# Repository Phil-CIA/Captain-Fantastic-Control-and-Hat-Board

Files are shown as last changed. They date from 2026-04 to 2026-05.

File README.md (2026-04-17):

# Captain Fantastic Control and HAT Board

Focused hardware repo for the **Captain Fantastic Home Edition** base control board and its companion **HAT board**.

## Scope
Originally, the system was built around two main boards:
- the **matrix board**
- the **control board**

During development, the control section was split into two physical boards:
- the **base control board**
- the **HAT board**

The HAT board is **not** a revision of the control board. It is a companion board that was created when the original control board was split for development work.

> The separate lamp/switch matrix board work lives in the dedicated repo: `Pinball-Sw-Lamp-Matrix-`.

## Repo layout
- `hardware/control-board/` – current base control-board KiCad source for the next redesign pass
- `hardware/control-board/archive/` – older control-board snapshots and backup exports kept for reference
- `hardware/hat-board/` – companion HAT-board KiCad source
- `firmware/control-board/` – clean control-board firmware baseline for this repo
- `docs/` – project status, redesign notes, firmware migration notes, and bring-up checklists

## Current firmware definition draft
- `firmware/control-board/docs/SYSTEM_BEHAVIOR_CONTRACT.md` – working behavior contract for game states, scoring, audio policy, storage budget, diagnostics, and unresolved decisions to lock before code work
- `docs/SYSTEM_BEHAVIOR_CONTRACT.md` – top-level copy of the same contract for quick review/edit from the main docs area
- `docs/SYSTEM_BEHAVIOR_CONTRACT_MATRIX_BOARD.md` – matrix-board companion contract with lockable decisions and iterative question rounds for switch/lamp protocol behavior

## Current status
- New focused repo created on **2026-04-09**
- The current KiCad files uploaded to GitHub for both boards have been merged into this cleaned repo baseline
- A **.96-inch SSD1306-style I2C OLED** has also been added as a troubleshooting display for boot messages and local status during bring-up
- The next PCB change will likely **not** be the last one; the goal is to keep building and developing the hardware while collecting more real-world feedback
- Two redesign blockers are currently tracked:
  1. the **P-channel solenoid-drive section on the base board sees gate-drive conditions above the recommended `Vgs` range when used on the 26 V supply**
  2. the **HAT-board connector did not line up with the base board**, although there is a temporary development workaround

## Next steps
1. build the board for firmware development and, if needed for proof-of-life output checks, feed **both rails from a current-limited 5 V source** rather than the real 26 V supply
2. use `docs/INITIAL_STUFFING_GUIDE.md` and `docs/BENCH_STUFFING_CHECKLIST.md` to decide what to populate now versus later
3. follow the safe bring-up procedure in `docs/FIRST_POWERUP_CHECKLIST.md`
4. proceed with the **single-channel `TPS1H200A-Q1` smart high-side** respin direction using `docs/SOLENOID_DRIVER_SELECTION.md`, `docs/SINGLE_CHANNEL_SOLENOID_LAYOUT.md`, and `docs/SMART_SWITCH_CHANNEL_BLOCK.md` while continuing the clean firmware migration in `firmware/control-board/`

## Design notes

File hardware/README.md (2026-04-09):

# Hardware Notes

This folder contains the hardware design files for the Captain Fantastic base control board and its companion HAT board.

## Contents
- `control-board/` – current base control-board KiCad project and related files
- `control-board/archive/` – older control-board snapshots and backup exports kept for reference
- `hat-board/` – companion HAT-board KiCad project

## Guidance
- The HAT board is **not** a revision of the control board; it was created when the original control board was split during development.
- Treat the uploaded KiCad files now stored under `hardware/` as the **authoritative baseline** for the next redesign pass.
- As redesign decisions are made, keep the active source clearly identified and move stale artifacts out of the way.

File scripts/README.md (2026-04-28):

# BOM Conversion Scripts

## jlc_to_digikey_bom.py

Converts an existing JLC-style BOM CSV or LCSC quotation XLS into:

- a Digi-Key upload CSV that only contains safe rows with real part-number identity
- a Digi-Key candidate BOM CSV
- an unresolved-items CSV for rows that still need lookup or manual review

This is intended to preserve the current KiCad to JLC export workflow and move the Digi-Key conversion into a post-export step.

### Usage

```powershell
c:/Users/forch/GitHub/Captain-Fantastic-Control-and-Hat-Board/docs/.venv/Scripts/python.exe scripts/jlc_to_digikey_bom.py "c:/path/to/project BOM.csv"
```

LCSC quotation workbook input:

```powershell
c:/Users/forch/GitHub/Captain-Fantastic-Control-and-Hat-Board/docs/.venv/Scripts/python.exe scripts/jlc_to_digikey_bom.py "c:/Users/forch/Downloads/export_project_20260424_030448.xls"
```

Optional lookup table:

```powershell
c:/Users/forch/GitHub/Captain-Fantastic-Control-and-Hat-Board/docs/.venv/Scripts/python.exe scripts/jlc_to_digikey_bom.py "c:/path/to/project BOM.csv" --lookup-csv scripts/commodity_lookup_template.csv
```

Optional reusable cross-reference sheet:

```powershell
c:/Users/forch/GitHub/Captain-Fantastic-Control-and-Hat-Board/docs/.venv/Scripts/python.exe scripts/jlc_to_digikey_bom.py "c:/Users/forch/Downloads/export_project_20260424_030448.xls" --cross-reference-csv "c:/Users/forch/Downloads/export_project_20260424_030448_Cross_Reference.csv"
```

Optional master reusable cross-reference sheet:

```powershell
c:/Users/forch/GitHub/Captain-Fantastic-Control-and-Hat-Board/docs/.venv/Scripts/python.exe scripts/jlc_to_digikey_bom.py "c:/Users/forch/OneDrive/JLCPCB files/Pinnall Control Board/Hat Board/Hat board BOM.csv" --master-cross-reference-csv "c:/Users/forch/OneDrive/JLCPCB files/master_cross_reference.csv"
```

### Output files

For an input file named `Project BOM.csv`, the script writes:

- `Project_BOM_DigiKey_Upload.csv`
- `Project_BOM_DigiKey_Simple_Upload.csv`
- `Project_BOM_DigiKey_Candidate_BOM.csv`
- `Project_BOM_Unresolved.csv`

The files are written next to the source BOM unless `--output-dir` is provided.

### Status values

- `Auto`: manufacturer and manufacturer part number were already present and carried through.
- `Lookup`: the row looks like a commodity passive and should be resolved through a preferred Digi-Key mapping.
- `Manual_Review`: fit-critical, generic, or incomplete rows that should not be guessed.

### Cross-reference guidance

- Use `--cross-reference-csv` to feed the reusable review sheet built by `build_cross_reference_sheet.py` directly into the converter.
- Use `--master-cross-reference-csv` to feed the combined reusable master sheet built by `build_master_cross_reference_sheet.py` into the converter.
- The converter matches cross-reference sheets by `LCSC_PN` first and `Manufacturer_PN` second.
- If both `--cross-reference-csv` and `--master-cross-reference-csv` are provided, the project sheet wins and the master sheet is only used as fallback.
- If a row in the cross-reference sheet has `DigiKey_PN`, that value is treated as the preferred Digi-Key identity.
- If `DigiKey_PN` is blank but `Onshore_Preferred_PN` is populated with supplier `Digi-Key` or left blank, the converter will also treat that as a Digi-Key-safe preferred part number.
- Candidate and unresolved outputs now include `Preferred_Onshore_PN`, `Preferred_Onshore_Supplier`, and `Cross_Reference_Match` columns so you can see exactly where the mapping came from.

### Upload guidance

- Use the `*_DigiKey_Upload.csv` file for Digi-Key import tests.
- If Digi-Key keeps importing the wrong identity from a wide CSV, use `*_DigiKey_Simple_Upload.csv` first. It contains only `Manufacturer Part Number`, `Quantity`, and `Manufacturer Name` to reduce mapping ambiguity.
- Use the `*_DigiKey_Candidate_BOM.csv` file as a review sheet, not as the first upload target.
- The upload CSV intentionally omits unresolved rows so Digi-Key does not try to match reference designators like `D1` or `J4` as if they were part numbers.
- If you have an LCSC `export_project_*.xls` quotation workbook, prefer that over the raw KiCad/JLC BOM CSV. It already contains LCSC matched manufacturer part numbers and produced a much stronger Digi-Key upload file in validation.

### Current limitations

- The script does not yet fetch Digi-Key part numbers from the web.
- Commodity passives need a lookup table or manual preferred-stock assignment to fill `DigiKey_PN`.
- Connector, module, display, and other fit-critical items are intentionally conservative and stay in `Manual_Review` unless the source BOM already has reliable data.

## build_commodity_lookup_candidates.py

Scans one BOM or a directory tree of BOMs and produces a normalized passive lookup-candidates CSV.

### Usage

```powershell
c:/Users/forch/GitHub/Captain-Fantastic-Control-and-Hat-Board/docs/.venv/Scripts/python.exe scripts/build_commodity_lookup_candidates.py "c:/Users/forch/OneDrive/JLCPCB files"
```

This writes `commodity_lookup_candidates.csv` in the input directory by default.

Use this first if you do not already have a preferred Digi-Key passive list. It gives you one compact table of recurring passive specs to validate, instead of forcing you to review every project BOM separately.

## build_cross_reference_sheet.py

Builds a reusable cross-reference sheet from an LCSC `export_project_*.xls` quotation workbook.

### Usage

```powershell
c:/Users/forch/GitHub/Captain-Fantastic-Control-and-Hat-Board/docs/.venv/Scripts/python.exe scripts/build_cross_reference_sheet.py "c:/Users/forch/Downloads/export_project_20260424_030448.xls"
```

This writes `*_Cross_Reference.csv` next to the source workbook by default.

### Purpose

- Use this when Digi-Key import coverage is too low to be practical.
- The output is a deduplicated review sheet with LCSC part number, manufacturer, manufacturer part number, package, stock information, and blank columns for Digi-Key, Mouser, or another onshore preferred source.
- Fill this sheet once and reuse it across future builds instead of repeating cross-references project by project.

## build_digikey_cross_reference_sheet.py

Builds the first Digi-Key-history-seeded master cross-reference sheet from a standard Digi-Key order CSV export.

### Usage

```powershell
c:/Users/forch/GitHub/Captain-Fantastic-Control-and-Hat-Board/docs/.venv/Scripts/python.exe scripts/build_digikey_cross_reference_sheet.py "c:/path/to/digikey_order_history.csv"
```

This writes `*_DigiKey_Cross_Reference.csv` next to the source CSV by default.

### Expected input shape

The script targets the standard Digi-Key order CSV column shape:

- `Index`
- `DigiKey Part #`
- `Manufacturer Part Number`
- `Description`
- `Customer Reference`
- `Quantity`
- `Backorder`
- `Unit Price`
- `Extended Price`

### Purpose

- Use this as the Digi-Key-first seed dataset for the master sourcing sheet.
- It deduplicates rows by manufacturer part number when available, rolls up purchased quantity across repeated orders, and preserves the preferred Digi-Key ordering code.
- It intentionally leaves `LCSC_PN` and `Preferred_JLC` blank so the same sheet can be enriched later from LCSC quote workbooks.
- The standard Digi-Key CSV does not include manufacturer name or order date, so those fields are left blank or inferred conservatively until a richer export is available.

## build_master_cross_reference_sheet.py

Builds one combined reusable cross-reference sheet from a directory tree of JLCPCB project BOMs and LCSC quote workbooks.

### Usage

```powershell
c:/Users/forch/GitHub/Captain-Fantastic-Control-and-Hat-Board/docs/.venv/Scripts/python.exe scripts/build_master_cross_reference_sheet.py "c:/Users/forch/OneDrive/JLCPCB files"
```

This writes `master_cross_reference.csv` in the input directory by default.

### Supported inputs

- project BOM CSVs with columns like `Reference`, `Qty`, `Value`, `Footprint`, `LCSC`, and `Manufacturer`
- LCSC quotation `.xls` workbooks
- LCSC quotation `.xlsx` workbooks

### Purpose

- Use this when you want one master sourcing sheet instead of maintaining one cross-reference sheet per project.
- The script scans the directory tree, skips existing Digi-Key output CSVs, deduplicates repeated parts, and preserves which source files contributed each row.
- Rows from richer LCSC quote workbooks win over plain project BOM CSV rows when the same part appears in both places.

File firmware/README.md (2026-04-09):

# Firmware

Firmware work for this repo will live here as it is separated from the older mixed-purpose Captain Fantastic repository.

## Current contents
- `control-board/` – clean bring-up baseline plus legacy reference import for the base control board

## Plan
- keep the new active firmware clean and hardware-focused
- merge only the useful parts from the previous repo
- avoid dragging over old experimental clutter unless it is still needed

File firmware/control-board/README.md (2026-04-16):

# Control-Board Firmware

This folder is the clean firmware starting point for the **Captain Fantastic base control board** in this repo.

## Purpose
- keep a **clean bring-up-oriented `main.cpp`** for the new board work
- preserve the older control firmware as a **reference import** for merging features back in gradually
- support the current development plan: **build the full board, power both rails at 5 V for now if needed, and keep the real 26 V solenoid supply out of service**

## Layout
- `src/main.cpp` – integration orchestrator for runtime subsystems
- `src/command/command_runtime.cpp` – serial polling entrypoint and command dispatch
- `src/command/input_commands.cpp` – direct input command handlers
- `src/command/ota_commands.cpp` – OTA command handlers
- `src/command/audio_commands.cpp` – audio command handlers
- `src/display/displays.cpp` – migrated 7-segment display helper
- `src/input/direct_input_runtime.cpp` – direct input polling and state cache runtime
- `src/input/input_overlay_runtime.cpp` – direct-input overlay formatting, idle refresh, and event/status trigger glue
- `src/ota/ota_runtime.cpp` – staged OTA + Wi-Fi maintenance runtime
- `src/audio/audio_runtime.cpp` – MP3 playback, storage sync, and I2S fallback runtime
- `include/` – copied configuration and protocol headers needed for the control-board codebase
- `reference/legacy_control_main.cpp` – previous larger control firmware kept only as a source to merge from
- `docs/FIRMWARE_MODES_AND_SPLIT_2026-04-16.md` – system/test profile split contract
- `docs/CHAT_MEMORY_2026-04-16.md` – session memory and decisions captured in-repo

## Build profiles
The firmware now supports profile-based builds:
- `captain_control_system` (default): integration-safe behavior
- `captain_control_test`: test-heavy behavior and deeper diagnostics
- `captain_control_bringup`: retained for compatibility while migration continues

Profile selection is controlled by `CAPTAIN_APP_MODE_TEST` via `include/app_mode_config.h`.

Quick commands:
1. `platformio run -e captain_control_system`
2. `platformio run -e captain_control_test`

## Bring-up intent
The new `main.cpp` is intentionally minimal:
- boots the MCU
- initializes I2C and the score display
- scans the I2C bus and brings up the added **.96-inch SSD1306-style OLED** for local boot/status text when present
- keeps the solenoid outputs in a safe default state
- allows optional low-voltage output proof-of-life testing only when intentionally enabled

## Next firmware steps
1. separate test-only command behavior from shared command handlers while preserving one serial entrypoint
2. move over only the working gameplay / display / input pieces from `reference/legacy_control_main.cpp`
3. keep hardware-specific experiments and dead ends out of the system profile path
4. add the revised board pin or feature changes as they are confirmed on hardware

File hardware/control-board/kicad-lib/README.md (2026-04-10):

# Local KiCad Library (Repo-Tracked)

Put third-party symbols and footprints for this board here so paths are stable and git-tracked.

## Folder layout
- `symbols/` -> `.kicad_sym` files
- `footprints/` -> `.pretty` folders containing `.kicad_mod` files
- `3dmodels/` -> optional `.step` or `.wrl` files

## Recommended SnapMagic import naming
- symbol library file: `symbols/Snapmagic_TPS1H200A_Q1.kicad_sym`
- footprint library folder: `footprints/Snapmagic_TI_TPS1H200A_Q1.pretty/`

## KiCad path setup
In KiCad, when adding the library paths, use project-variable form so links survive on other machines:
- symbol library path: `${KIPRJMOD}/kicad-lib/symbols/Snapmagic_TPS1H200A_Q1.kicad_sym`
- footprint library path: `${KIPRJMOD}/kicad-lib/footprints/Snapmagic_TI_TPS1H200A_Q1.pretty`

`KIPRJMOD` resolves to the folder that contains the `.kicad_pro` file.

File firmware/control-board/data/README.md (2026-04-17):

# Control-Board Audio Test Files

Place MP3 files for control-board event playback here, then upload SPIFFS.

Recognized filenames (first match wins by event):

- Startup: `startup.mp3`, `rocket_man.mp3`, `crocodile_rock.mp3`
- Attract loop: `attract.mp3`, `rocket_man.mp3`
- Game start: `start.mp3`, `crocodile_rock.mp3`
- Bonus: `bonus.mp3`, `crocodile_rock.mp3`
- Game over: `game_over.mp3`, `rocket_man.mp3`
- High score: `high_score.mp3`, `rocket_man.mp3`

Upload steps from `firmware/control-board/`:

```powershell
pio run -e captain_control_bringup -t buildfs
pio run -e captain_control_bringup -t uploadfs
```

Current firmware behavior:

- On boot, firmware tries Startup MP3 once through MAX98357 I2S.
- You can trigger event clips from serial monitor with commands:
	- `mp3 help`
	- `mp3 startup`
	- `mp3 attract` (loops)
	- `mp3 start`
	- `mp3 bonus`
	- `mp3 gameover`
	- `mp3 hiscore`
	- `mp3 stop`
- If no suitable MP3 file exists for startup, firmware falls back to the built-in startup tone test.

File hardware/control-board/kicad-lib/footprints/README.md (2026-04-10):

# Footprints

Put project-specific KiCad footprint libraries here as `.pretty` folders.

Example for this work:
- `Snapmagic_TI_TPS1H200A_Q1.pretty/`

This file exists so the folder is tracked and visible in git/GitHub.

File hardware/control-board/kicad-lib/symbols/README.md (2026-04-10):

# Symbols

Put project-specific `.kicad_sym` files here.

Example for this work:
- `Snapmagic_TPS1H200A_Q1.kicad_sym`

This file exists so the folder is tracked and visible in git/GitHub.

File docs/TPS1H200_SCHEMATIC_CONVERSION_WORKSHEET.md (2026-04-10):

# TPS1H200 Schematic Conversion Worksheet

This worksheet is the direct bridge from the current discrete solenoid block to five repeated `TPS1H200A-Q1` channels.

Use this during an interactive KiCad schematic edit session.

## Scope
- Replace the old discrete solenoid drive path centered on `Q10`, `Q11`, and `Q18`
- Implement five channels for `S2`..`S6`
- Keep firmware-facing control naming aligned with `SD2`..`SD6`

## Existing anchor points in the current schematic
- old references:
  - `Q11` at [hardware/control-board/Pinball Control board.kicad_sch](hardware/control-board/Pinball%20Control%20board.kicad_sch#L33903)
  - `Q10` at [hardware/control-board/Pinball Control board.kicad_sch](hardware/control-board/Pinball%20Control%20board.kicad_sch#L41791)
  - `Q18` at [hardware/control-board/Pinball Control board.kicad_sch](hardware/control-board/Pinball%20Control%20board.kicad_sch#L42519)
- control/output rail labels already present:
  - `SD2` at [hardware/control-board/Pinball Control board.kicad_sch](hardware/control-board/Pinball%20Control%20board.kicad_sch#L11548)
  - `SD3` at [hardware/control-board/Pinball Control board.kicad_sch](hardware/control-board/Pinball%20Control%20board.kicad_sch#L11658)
  - `SD4` at [hardware/control-board/Pinball Control board.kicad_sch](hardware/control-board/Pinball%20Control%20board.kicad_sch#L12252)
  - `SD5` at [hardware/control-board/Pinball Control board.kicad_sch](hardware/control-board/Pinball%20Control%20board.kicad_sch#L12164)
  - `SD6` at [hardware/control-board/Pinball Control board.kicad_sch](hardware/control-board/Pinball%20Control%20board.kicad_sch#L11944)
  - `S2` at [hardware/control-board/Pinball Control board.kicad_sch](hardware/control-board/Pinball%20Control%20board.kicad_sch#L12208)
  - `S3` at [hardware/control-board/Pinball Control board.kicad_sch](hardware/control-board/Pinball%20Control%20board.kicad_sch#L12032)
  - `S4` at [hardware/control-board/Pinball Control board.kicad_sch](hardware/control-board/Pinball%20Control%20board.kicad_sch#L11636)
  - `S5` at [hardware/control-board/Pinball Control board.kicad_sch](hardware/control-board/Pinball%20Control%20board.kicad_sch#L11900)
  - `S6` at [hardware/control-board/Pinball Control board.kicad_sch](hardware/control-board/Pinball%20Control%20board.kicad_sch#L12010)
  - `+22vdc` at [hardware/control-board/Pinball Control board.kicad_sch](hardware/control-board/Pinball%20Control%20board.kicad_sch#L11592)

## Channel mapping to apply
| Channel | Control net | Output net | Supply net |
| --- | --- | --- | --- |
| U_S2 | SD2 | S2 | +22vdc |
| U_S3 | SD3 | S3 | +22vdc |
| U_S4 | SD4 | S4 | +22vdc |
| U_S5 | SD5 | S5 | +22vdc |
| U_S6 | SD6 | S6 | +22vdc |

## Required per-channel support items
- local decoupling capacitor at device supply pin
- CL programming population (value per bench tuning)
- DELAY configuration population (mode per bench tuning)
- FAULT routing to test point and optional MCU net

## Execution checklist
1. Add/import `TPS1H200A-Q1` symbol to the project schematic library.
2. Place five channel symbols (`U_S2`..`U_S6`) near existing solenoid output region.
3. Rewire control nets: `SD2`..`SD6` to channel inputs.
4. Rewire outputs: channel outputs to `S2`..`S6`.
5. Rewire supply and return: `+22vdc` and ground per channel.
6. Add CL, DELAY, and FAULT support components per channel.
7. Remove legacy discrete path parts no longer used (`Q10`, `Q11`, `Q18`, and dependent gate-drive parts).
8. Run ERC and resolve all new issues.
9. Mirror chosen CL/DELAY settings in `docs/TPS1H200_CL_DELAY_BENCH_TABLE.md`.

## Note on tooling
The project currently does not include a dedicated `.kicad_sym` library in-repo, so symbol insertion is best done interactively in KiCad to avoid malformed schematic edits.

## SnapMagic import and repo sync steps
Use this flow to keep your local KiCad setup and git repo aligned.

1. Copy your downloaded SnapMagic symbol file into:
  - `hardware/control-board/kicad-lib/symbols/`
2. Copy your downloaded SnapMagic footprint `.pretty` folder into:
  - `hardware/control-board/kicad-lib/footprints/`
3. In KiCad Schematic Editor, open **Preferences -> Manage Symbol Libraries**.
4. Add your symbol library as **Project Specific** and paste this in the path/address box:
  - `${KIPRJMOD}/kicad-lib/symbols/<your_symbol_file>.kicad_sym`
5. In KiCad PCB Editor (or Preferences), open **Manage Footprint Libraries**.
6. Add your footprint library as **Project Specific** and paste this in the path/address box:
  - `${KIPRJMOD}/kicad-lib/footprints/<your_footprint_library>.pretty`
7. Save library tables and place the symbol in schematic.
8. In terminal, run:
  - `git add hardware/control-board/kicad-lib`
  - `git add hardware/control-board/Pinball Control board.kicad_sch`
  - `git add hardware/control-board/Pinball Control board.kicad_pcb`
  - `git commit -m "Add project-local TPS1H200 symbol and footprint libraries"`
  - `git push`

This keeps your symbol and footprint paths portable and tracked in the repo.

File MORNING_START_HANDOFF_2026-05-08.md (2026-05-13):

# Morning Start Handoff - 2026-05-08

Status: Ready for next-session execution.
Purpose: Start clean in the morning with one practical sequence that gets from bring-up toward playable behavior while keeping repo hygiene moving.

## Repositories In Scope
1. https://github.com/Phil-CIA/Captain-Fantastic-Control-and-Hat-Board
2. https://github.com/Phil-CIA/Pinball-Sw-Lamp-Matrix-
3. https://github.com/Phil-CIA/Captain-Fantastic-home-edition

## Current Snapshot

### Control-and-Hat-Board (main at d07bf7c)
- New handoff present: SOLENOID_BRINGUP_HANDOFF_2026-05-08.md
- Solenoid state:
  - S3/S4/S5/S6 working on TPS path
  - S2 (outhole) still insufficient force on TPS even with aggressive current-limit tuning
- Firmware currently in test profile behavior for focused S2 validation:
  - S2 pulse set to 100 ms
  - Single-channel repeated test mode enabled
- GPIO init-order fix applied to reduce boot glitch risk on GPIO5 path

### Pinball-Sw-Lamp-Matrix- (main at b2cbb86)
- Deterministic row scheduler and SR timing stabilization work already merged previously
- CI pin fix for espressif32 version already merged previously
- Latest commit is doc-only

### Captain-Fantastic-home-edition
- Not locally checked out in this workspace during this session
- Still part of integration scope as legacy behavior reference source

## Morning Start Plan (Execution Order)

1. Hardware path first: complete S2 outhole relay workaround bench wiring and validate force.
2. After S2 force is reliable, revert control test loop from single-channel S2 back to full five-channel cycle and confirm all five channels repeat cleanly.
3. Verify the four pending switch paths explicitly and log results:
   - Tilt
   - Maintenance/Test
   - Easy
   - Start
4. Define and lock operating mode behavior notes before deeper gameplay coding:
   - Boot
   - Test/Service
   - Attract
   - Gameplay
   - Degraded/Error
5. Begin gameplay coupling implementation once switch and mode behavior checks are captured:
   - Switch edge to solenoid action mapping
   - Initial score increment path
   - Lamp state update path

## Repo Cleanup Stream (Run In Parallel)

1. In each repo, create a dedicated handoff archive folder.
2. Move handoff/transfer session docs into that folder without renaming date-stamped files.
3. Add one chronological journey index per repo linking all handoffs in date order.
4. Refresh stale top-level status docs after technical state is validated.

## Immediate First Commands For Morning

1. Pull all repos on start:
   - Control-and-Hat-Board
   - Pinball-Sw-Lamp-Matrix-
   - Captain-Fantastic-home-edition
2. Build and flash control-board test profile to verify baseline before hardware edits.
3. Execute relay workaround validation checklist from SOLENOID_BRINGUP_HANDOFF_2026-05-08.md.

## Risks To Watch

- Do not start gameplay callback wiring while S2 hardware force is unresolved.
- Keep test-mode changes isolated and reversible so production path is not polluted.
- Preserve historical handoff filenames when reorganizing docs to avoid losing timeline continuity.

## Session End State

- Handoff written and pushed target: this file
- Next operator action: begin at Morning Start Plan step 1

## Switch Recovery Addendum (2026-05-11)

### What We Know

1. Known-good matrix checkpoint exists from the working perspective: `aca9ac0` (matrix chunked OLED milestone, 2026-05-05).
2. Latest handoff (2026-05-10) indicates transport health is stable:
   - `rx_pkts` increasing on matrix
   - `wr_ok` and `rd_ok` increasing on control
   - checksum/reject alarms no longer noisy
3. Current failure mode is switch isolation/mapping quality, not basic link up/down.
4. Current control firmware has a strict burst-drop guard (`MATRIX_MAX_RISING_EDGES_PER_POLL = 4`) that can suppress entire poll windows.
5. Mapping-mode concept (lamps forced off during mapping capture) is a valid mitigation and must be verified in the exact flashed binary before further tuning.

### What We Need To Know

1. Are real switch presses being dropped by filtering thresholds (control side) versus lost on matrix scan/debounce (matrix side)?
2. Is lamp-off mapping mode active in the actual build being tested?
3. Did row/column mapping or active-row assumptions drift between `aca9ac0` and current cleanup state?
4. Do dropped-burst counts correlate directly with deliberate press windows?
5. Is the current debounce cadence suppressing short but valid press events?

### Recovery-First Plan (No Gameplay Features Until This Passes)

1. Freeze A/B references:
   - A = known-good behavior target (`aca9ac0`)
   - B = current behavior target (latest split-protocol head)
2. Run identical captures for A and B on same hardware and wiring:
   - 30s quiet baseline
   - 15-20 deliberate presses on one target switch
   - repeat on two additional switches
3. Compare outcomes:
   - If A clean and B fails, software regression confirmed.
   - If both fail, prioritize hardware/wiring/mechanics isolation.
4. If software regression is confirmed, isolate in this order:
   - force lamp-off mapping mode
   - temporarily relax burst-drop threshold for capture build
   - reduce debounce ticks for capture build
   - verify row/col mapping and active-row limits
5. Lock acceptance gate before gameplay coupling resumes:
   - each tested switch yields one dominant bit in press windows
   - intentional presses are not suppressed by burst filter

### Hard Stop Rule

Do not proceed to scoring, gameplay callback wiring, or mode expansion until the switch recovery acceptance gate is met and repeatable.

---

## Integration Reference: Recovery-to-Gameplay Plan (May 12–13)

A comprehensive next-phase execution plan has been created to advance from baseline validation (timing locked, I2C healthy, S3–S6 solenoid working) toward playable behavior.

**See**: [RECOVERY_TO_GAMEPLAY_PLAN_2026-05-12.md](RECOVERY_TO_GAMEPLAY_PLAN_2026-05-12.md)

### Key Highlights from That Plan

1. **What We Know** (May 12 End-of-Day Status)
   - Matrix timing locked and acceptance test passed
   - I2C transport stable under continuous polling
   - Solenoid S3–S6 verified working on TPS
   - S2 relay workaround pending installation (parallel stream, not blocking)

2. **What We Need To Know** (Blocking Criteria)
   - Switch detection quality: one dominant bit per press (A/B capture validation required)
   - Tilt & Start direct-input paths clean (no cross-talk with matrix)
   - Lamp delivery to headbox working without frame corruption

3. **S2 Coil Protection Policy** (During Relay Installation & Limited Testing)
   - Max 2–3 activations per group
   - 10–15s cool-down between attempts
   - 60s cool-down between groups
   - Operator observes coil temperature/sound for abort signals
   - Policy suspended after relay installation complete

4. **Parallel Work Streams** (May 13–14, ~6–8 hours total)
   - **Stream A (Hardware)**: Install S2 relay, verify 24V force recovery (~2–4 hours)
   - **Stream B (Software)**: Execute switch A/B capture validation, run gate analysis, apply feature gates if needed (~4–6 hours)

5. **Gameplay Integration** (Begins After Switch Gate Passes)
   - Mode scaffolding (Boot → Test → Attract → Gameplay → Error)
   - Solenoid coupling (switch edge → solenoid action)
   - Score & lamp state wiring

6. **Definition of Done**
   - Switch validation gate passed ✅
   - S2 coil protection enforced or relay installed ✅
   - One end-to-end switch→solenoid→lamp flow working ✅
   - All docs updated and pushed ✅

**Execution Sequence**: Start with parallel streams (relay install + switch captures). Switch gate result drives gameplay integration timeline. Reference that plan for detailed command sequences, feature gates, and risk mitigations.

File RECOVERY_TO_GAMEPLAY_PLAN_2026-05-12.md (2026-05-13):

# Recovery-to-Gameplay Integration Plan — 2026-05-12

**Status**: Ready for immediate execution (May 13–14).  
**Purpose**: Advance from hardware validation baseline (matrix timing locked, I2C link healthy, S3–S6 solenoid working) to playable behavior while managing parallel hardware work (S2 relay installation) and switch validation gates.

---

## What We Know (As of May 12 End-of-Day)

✅ **Matrix Timing Baseline Locked**
- Deterministic row scheduler: Blank=50µs, Settle=50µs, Hold post-settle
- One-row-active invariant maintained
- Acceptance test passed (no timing violations detected over 60s baseline)
- Checkpoint commit: `ec90aa2` (home-edition) with timing contract doc

✅ **I2C Transport Healthy**
- Matrix slave at 0x24 stable under continuous polling
- Control master at 100 kHz polls every 15ms without checksum/rejection alarm noise
- Packet counters (`rx_pkts`, `wr_ok`, `rd_ok`) increasing monotonically
- Burst filter active: 4-rising-edge-per-poll threshold suppresses scan noise

✅ **Solenoid S3–S6 Verified**
- TPS1H200A driver path working for kitchen drop (S3), orbit (S4), ramp (S5), scoop (S6)
- Pulse widths {45, 45, 45, 40} ms confirmed in hardware testing
- Force/behavior observed as expected on bench

⚠️ **Solenoid S2 (Outhole) in Workaround**
- TPS1H200A current-limit insufficient even at 0Ω (coil/hardware constraint)
- Relay solution implemented: GPIO23 → automotive 24V relay, full 24V fed to outhole solenoid
- **Relay installation NOT YET COMPLETE** (happening May 13 in parallel)
- Until relay installed: **S2 protected by manual testing limits** (see S2 Coil Protection Policy below)

✅ **Matrix LED Heartbeat Implemented**
- WS2812 RGB status LED on GPIO8 via native RMT
- Green = healthy, Red = I2C fault
- 500ms toggle cadence

✅ **Control Board Heartbeat GPIO Conflict Fixed**
- Moved from GPIO2 (hardware conflict with headbox 74HC595 DATA line) to GPIO16
- No impact on matrix communication

---

## What We Need To Know (Blocking Criteria for Gameplay)

### 1. Switch Detection Quality & Dominance
**Criterion**: One dominant bit per switch, no suppression of real presses by filtering.

- **Current State**: Multiple bits rising per press window; unclear which is true signal vs. noise
- **Method**: A/B capture on both machines
  - A = known-good checkpoint (`aca9ac0`, matrix milestone from May 5)
  - B = current code (May 12 head)
  - Identical hardware wiring, same test sequence
  - 30s quiet baseline + 15–20 deliberate presses per switch on 3 target switches
- **Expected Result**: A shows 1 dominant bit per press, B either matches or shows clear regression pattern
- **Acceptance Gate**: Must demonstrate either current code passes OR clear root cause (burst threshold too strict, debounce too conservative, mapping mode off)

### 2. Tilt & Start Direct-Input Paths
**Criterion**: Both inputs debounce cleanly, no cross-talk with matrix polling.

- **Current State**: GPIO-based debounce at 5ms polling, 3-tick threshold
- **Method**: Manual press test, verify no spurious edges during matrix scan
- **Acceptance Gate**: 20 deliberate presses per input, zero missed detections, zero false positives

### 3. Lamp Delivery to Headbox
**Criterion**: 74HC595 lamp frame writes succeed without corruption.

- **Current State**: Lamp frame compose + XOR checksum in control code
- **Method**: Capture lamp register state via I2C read (0x00–0x07) after write, verify bit pattern
- **Acceptance Gate**: 10 intentional lamp updates, all match commanded state ± latency

---

## S2 Coil Protection Policy (During Relay Installation & Limited Testing)

### When To Use
- **Before relay installed**: Any manual testing of S2 solenoid must follow these limits
- **During relay installation**: Protects hardware from repeated activation thermal stress
- **After relay installed**: Revert to normal operation; protection policy suspended

### Limits
| Parameter | Value | Rationale |
|---|---|---|
| **Max activations per group** | 2–3 tries | Coil thermal time constant ~30–60s; risk of overtemp above 3 |
| **Cool-down between attempts** | 10–15s | Minimum for coil to dissipate heat before next try |
| **Cool-down between groups** | 60s | Reset to baseline before next validation sequence |
| **Stop condition** | If coil feels warm OR stalls mid-pulse | Immediate abort; let cool 5–10 min before resume |
| **Operator observation** | Listen/feel for coil hum; watch for current stall | Audible signature change = risk signal |

### Enforcement
1. **Operator logs attempt count** per group (manual tally on bench sheet)
2. **GPIO access disabled** after group-max reached; requires manual override/code change to resume
3. **Automatic abort** if test firmware detects current abnormality (implementation TBD after relay install)

### Example Session
```
Group 1: Attempts 1, 2, 3 → cool 60s
Group 2: Attempts 1, 2, 3 → cool 60s
Group 3: Attempts 1 → coil warm detected → STOP
Wait 10 min, inspect coil, proceed only if cool
```

---

## Execution Plan (May 13–14)

### Parallel Work Streams (Can Run Simultaneously)

#### Stream A: Hardware (S2 Relay Installation) — ~2–4 hours
1. Install automotive relay on S2 driver bench
2. Wire GPIO23 → relay control input
3. Wire 24V supply through relay NO contact → outhole solenoid
4. Verify relay click/engagement during test pulse (GPIO23 high)
5. Test solenoid force recovery: full 24V, no current-limit bottleneck
6. If successful: commit "S2 relay workaround complete, force verified"
7. Resume normal operation; protection policy no longer in effect

#### Stream B: Software (Switch Validation Gate) — ~4–6 hours
1. **Start**: Fetch latest on all three repos (should be clean as of this morning)
2. **Phase 1 – A/B Capture Setup** (1–1.5 hours)
   - Check out `aca9ac0` (known-good) to separate branch/tag in matrix repo
   - Build & flash known-good binary to matrix board (or USB-connected bench board)
   - Build & flash current code (`ec90aa2`) to control board
3. **Phase 2 – Known-Good Baseline** (1–2 hours)
   - Boot matrix with `aca9ac0` firmware
   - Run 30s quiet baseline, capture switch register reads
   - Press target switch (e.g., Easy, Tilt, Start) 15–20 times, log per-press register state
   - Repeat on 2–3 additional switches
   - Save capture as `SWITCH_CAPTURE_A_2026-05-13_knowngood.txt`
4. **Phase 3 – Current Code Capture** (1–2 hours)
   - Flash current matrix firmware (`ec90aa2`)
   - Repeat Phase 2 sequence identically
   - Save as `SWITCH_CAPTURE_B_2026-05-13_current.txt`
5. **Phase 4 – Analysis & Gating Decision** (30–60 min)
   - Compare bit dominance, burst-drop counts, debounce stability
   - If A clean & B fails: Apply feature gates (mapping mode force-on, burst threshold relaxed, debounce reduced)
   - Re-test with gates applied
   - Document gate settings in feature gate control table
   - If both pass or regression confirmed & recoverable: Accept gate and proceed to gameplay coupling

### Gameplay Integration (Begins After Switch Gate Passes)
1. **Mode Scaffolding** (2–3 hours)
   - Define mode enum: Boot → Test → Attract → Gameplay → Error
   - Wire mode transitions (currently missing)
   - Boot sets mode=Test; needs manual mode-select logic
2. **Solenoid Coupling** (2–3 hours)
   - Wire switch edge callback → solenoid pulse lookup
   - Example: Start button → S6 (scoop) + advance to Attract
   - Example: Tilt → S2 (outhole) drain + Gameplay abort
3. **Score & Lamp State** (3–4 hours)
   - Implement basic score increment per action (e.g., +10 per switch)
   - Wire lamp updates to score display (7-segment or dot matrix)
   - Verify lamp frames deliver to headbox without corruption

### Definition of "Done" for This Milestone
✅ Switch validation gate passed (dominance confirmed, no filtering loss)  
✅ Tilt & Start inputs working without cross-talk  
✅ S2 relay installed (if parallel work completes) OR S2 protection policy enforced (if pending)  
✅ Mode scaffolding locked  
✅ One complete switch→solenoid→lamp flow works end-to-end (e.g., Start press → scoop fire → attract mode lamp updates)  
✅ All handoff docs updated with gate results and next blockers  
✅ Repos committed and pushed clean

---

## Blocking Criteria (Do NOT Proceed Without)

### Hard Stop: Switch Recovery Gate
- **Gate**: Each tested switch must yield one dominant bit per press window
- **Measurement**: A/B captures show no regression OR regression traced to recoverable feature gate
- **Enforcement**: Gameplay callback wiring blocked until gate signed off

### Hard Stop: Solenoid S2 Coil Protection
- **Gate**: Manual testing limits enforced OR relay installed and verified working
- **Measurement**: No coil thermal failures during limited testing window
- **Enforcement**: S2 cannot pulse without explicit operator override if limits violated

### Soft Gate (Non-Blocking But Document)
- Mode behavior wiring deferred: mode-select logic not yet implemented
  - Will be added incrementally after switch validation passes
  - Test/Service mode will not auto-transition until implementation complete

---

## Risks & Mitigations

| Risk | Impact | Mitigation |
|---|---|---|
| Switch A/B captures inconclusive | 2–4 day delay before gameplay coding | Run captures on both boards; if one fails, priority is hardware/wiring isolation, not code tuning |
| S2 relay install delays | Coil protection limits must persist longer | Parallel stream: if relay stalls, continue switch validation; S2 testing deferred to next session |
| Tilt input crosstalk with matrix polling | Tilt abort loses reliability during gameplay | Validate Tilt debounce on bench before committing to full mode integration |
| Lamp 74HC595 writes corrupt | Attract/Gameplay lamp updates fail | Test lamp delivery gate before score display loop implementation |

---

## Repo Commit & Push Checklist

- [ ] Create this document: `RECOVERY_TO_GAMEPLAY_PLAN_2026-05-12.md`
- [ ] Append reference section to `MORNING_START_HANDOFF_2026-05-08.md`
- [ ] Commit both to Captain-Fantastic-Control-and-Hat-Board
- [ ] Verify no outstanding changes in other two repos (should be clean)
- [ ] Push to GitHub (all three repos)
- [ ] Verify GitHub workflows / CI runs (if any) do not block

---

## Next Session Continuation (After Completion)

1. Review captured switch data from A/B analysis
2. Evaluate feature gate necessity (if any)
3. Publish gate-pass or gate-fail decision as new handoff (e.g., `SWITCH_GATE_RESULT_2026-05-13.md`)
4. If passed: Begin mode scaffolding in control code
5. If failed: Debug feature gates and re-test; do not unblock gameplay coupling until gate passes

---

## Historical Context

- **May 1–3**: Timing archaeology, CI version fix (espressif32 7.0.0 regression)
- **May 5**: Known-good matrix checkpoint (`aca9ac0`) created at OLED debug milestone
- **May 8**: Solenoid bring-up and S2 relay workaround planning
- **May 10–12**: Protocol hardening, I2C link health validation, timing contract locked
- **May 12 EOD**: Recovery-to-gameplay plan verbal agreement; S2 protection policy defined; parallel work approved
- **May 13**: (This session) Formalize plan into doc, commit, and execute

---

**End of Recovery-to-Gameplay Integration Plan**

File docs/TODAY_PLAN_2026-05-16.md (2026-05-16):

# Today Plan - 2026-05-16

Purpose: Execute a clean, low-risk path from repo cleanup and bench validation to initial game audio integration.

## Source of truth used for this plan
- `MACHINE_TRANSFER_HANDOFF_2026-04-30.md` (latest in working tree)
- `FIRMWARE_INTEGRATION_HANDOFF_2026-04-29.md`
- Commit `f7ed650` history docs:
  - `MORNING_START_HANDOFF_2026-05-08.md` (includes switch recovery addendum)
  - `RECOVERY_TO_GAMEPLAY_PLAN_2026-05-12.md`

Note: commit `7e1a312` is not present in this repository refs after fetch. If that hash is from another repo, use that repo as the source for any additional handoff notes.

## Hard gates for today
1. Do not start gameplay/audio coupling until switch recovery gate passes.
2. Keep S2 protections active unless relay workaround is fully installed and verified.
3. If matrix link health fails for ~1000 ms, stop and fix transport first.

## Execution order

### Phase 1 - Repo and workspace cleanup (matrix + control)
Goal: clean handoff history and reduce confusion before bench work.

1. Pull latest in all repos:
   - Captain-Fantastic-Control-and-Hat-Board
   - Pinball-Sw-Lamp-Matrix-
   - Captain-Fantastic-home-edition
2. In each repo, create/verify a handoff archive folder.
3. Move dated handoff/transfer docs into archive (no renames).
4. Add/update one chronological index page listing all handoffs.
5. Confirm top-level status doc matches actual firmware/hardware state.

Exit criteria:
- No ambiguous "latest handoff" state.
- Session docs are organized and discoverable.

### Phase 2 - Matrix + control bench verification
Goal: prove stable control/matrix baseline before feature work.

1. Flash/verify known test baseline on control board.
2. Verify matrix transport health:
   - packet and read/write counters increase cleanly
   - no sustained checksum/reject noise
3. Run switch quality gate captures:
   - 30s quiet baseline
   - 15-20 deliberate presses on at least 3 target switches
   - verify one dominant bit per intentional press window
4. Validate direct inputs:
   - Tilt: 20 deliberate presses, no misses/false positives
   - Start: 20 deliberate presses, no misses/false positives
5. Verify lamp delivery path:
   - 10 intentional updates, readback matches commanded state

Exit criteria:
- Switch gate passed.
- Direct-input debounce clean.
- Lamp write/readback reliable.

### Phase 3 - S2 status check (parallel stream)
Goal: close S2 risk before broader gameplay behavior.

1. If relay workaround is still pending, enforce manual S2 limits:
   - max 2-3 activations per group
   - 10-15s between attempts
   - 60s between groups
2. If relay is installed, verify full-force outhole behavior and retire temporary limit policy.

Exit criteria:
- S2 is either protected by policy or verified on relay path.

### Phase 4 - Integrate game audio and sound routines
Start only if Phases 2 and 3 pass.

1. Wire switch/solenoid events to existing audio queue hooks.
2. Map first-pass sounds:
   - bumper hit -> bumper sound
   - sling hit -> sling sound
   - outhole/drain -> drain sound
   - start/game transition -> mode transition sound
3. Validate timing:
   - no audible lag on event playback
   - no event spam from bounce/noise
4. Validate interference:
   - no added noise or resets during solenoid events
5. Capture event-to-sound mapping and commit notes.

Exit criteria:
- At least one end-to-end flow confirmed:
  switch -> solenoid action -> lamp update -> sound effect.

## End-of-day deliverables
1. Updated handoff doc with pass/fail gates and blockers.
2. Commit(s) for:
   - docs cleanup/index updates
   - any gate or config changes
   - audio wiring changes (if started)
3. Short next-session start checklist (first 5 commands + first 3 validation checks).

## If blocked
- If switch gate fails: stop gameplay/audio work and continue only with capture + isolation.
- If S2 force remains unresolved: keep S2 out of normal gameplay path and proceed with non-S2 audio/event wiring only.

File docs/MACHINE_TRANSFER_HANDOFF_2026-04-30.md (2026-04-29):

# Machine Transfer Handoff (2026-04-30)

Purpose: resume from today's verified firmware state and execute the next bench step with a tracked plan.

## Where we are right now
- Matrix/display board (`COM4`) upload path is confirmed and working.
- Control board (`COM5`) upload path is confirmed and working.
- Control board firmware now self-identifies at boot with version/build/signature:
  - `FW: control-board | build=<env>-<unix_time> | sig=<hex> | built=<date time>`
- TEST profile on control board was flashed and validated:
  - profile prints `Profile: TEST`
  - output test cycles `S2..S6` in serial output
- Matrix link may still be degraded at boot; TEST output cycling remains enabled in that condition.

## Safety boundary for morning bench
- Use 5V current-limited bench power for LED/logic validation.
- Keep real 26V coil rail disconnected.
- Validate visible outputs first, then command-path behavior.

## Tracked morning plan
1. Power and baseline checks
- Connect control board and matrix/display board.
- Confirm ports (`COM4` matrix/display, `COM5` control).
- Open control serial monitor and capture boot identity line.

2. Validate output activity with known-good TEST profile
- Confirm repeating `Output test -> S2..S6` lines.
- Confirm corresponding LED/driver indicators on 5V bench setup.

3. Playfield light control path test (requested focus)
- Keep control board online and matrix/display board connected.
- Move from autonomous test pulsing to commanded light behavior validation.
- Capture which commands/states map to which observed playfield lamps.

4. Stabilize and document
- Record pass/fail per lamp group.
- Record any non-responsive channels and wiring notes.
- Decide if we stay in TEST or reflash SYSTEM at end of session.

## Known-good commands
From `firmware/control-board`:

```powershell
C:\Users\user\.platformio\penv\Scripts\platformio.exe run -e captain_control_test --target upload --upload-port COM5
C:\Users\user\.platformio\penv\Scripts\platformio.exe device monitor --port COM5 --baud 115200
```

From matrix/display firmware folder:

```powershell
C:\Users\user\.platformio\penv\Scripts\platformio.exe run -e display_board --target upload --upload-port COM4
```

## Notes for first message tomorrow
- Priority is playfield-light control from control board, not just autonomous test cycling.
- Keep updates concise with direct hardware-observation checkpoints.
- Continue using firmware identity line to verify exactly what is running before each test.

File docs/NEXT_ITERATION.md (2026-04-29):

# Next Iteration / Parking Lot

This file is the parking lot for the control-board and HAT-board redesign.

## Current focus
- keep the current hardware buildable for development while planning the next PCB revision
- assemble the board and do the first bring-up on **5 V only** for firmware development
- leave the **26 V solenoid supply disconnected** until the base-board P-channel `Vgs` issue has a safe workaround or redesign
- continue using the **HAT-board connector workaround** for development, while leaving the proper alignment fix on the next PCB revision list
- keep only the control-board / HAT-board material needed for this effort
- identify the authoritative KiCad files for the next revision

## Known issues to document next
- Issue 1: the **P-channel solenoid-drive section on the base control board has a gate-drive / `Vgs` problem on the 26 V solenoid supply**; this is the same underlying concern already seen on the matrix board.
- Issue 2: the **connector for the HAT board did not line up correctly** with the matching connection on the base board, but there is a usable temporary workaround for development.

## Parking lot
- decide whether the next architecture remains split between a **base board** and a **HAT board**, or gets recombined later
- keep connector / pin-mapping notes near the hardware source of truth
- capture any assembly or mechanical fit problems as soon as they are observed
- use `docs/REV_B_ACTION_LIST.md` as the working checklist for the next schematic pass

## Notes log
- 2026-04-09: new focused repo created from the larger Captain Fantastic project so the control-board and HAT-board redesign can proceed cleanly.
- 2026-04-09: current KiCad files for both the control board and the HAT board were uploaded and folded into the cleaned repo baseline.
- 2026-04-09: clarified that the HAT board is a companion board created by splitting the original control board during development, and documented the first two must-fix redesign issues.
- 2026-04-09: current development plan is to build the board for firmware work and power it with **5 V only** at first, with the 26 V solenoid path left disconnected.
- 2026-04-11: the revised control-board PCB was routed and the main `TPS1H200A-Q1` footprint-library mismatch was relinked to the repo-local footprint library.
- 2026-04-11: next step is final DRC / manufacturing-output generation and then ordering the revised board.
- 2026-04-12: Rev 1 PCB order placed.
- 2026-04-12: Rev 1 BOM/parts order placed.
- 2026-04-12: next operational step moved to receive/inspect/assemble and follow `docs/REV1_POWERUP_ON_ARRIVAL.md`.
- 2026-04-29: control-board firmware now emits build identity (`FW/build/sig/built`), serial switch logging is throttled/summarized, and TEST profile output cycling (`S2..S6`) was validated on COM5 for 5V bench proof-of-life.

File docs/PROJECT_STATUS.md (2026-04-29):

# Project Status

## Summary
This repo tracks the **Captain Fantastic base control board** and its companion **HAT board** as a focused hardware project.

## Current state (2026-04-12)
### Hardware
- The current KiCad files uploaded to this repo are now the authoritative baseline for both boards
- The machine originally had two main boards: the matrix board and the control board
- During development, the control board was split into a **base control board** plus a **HAT board**
- The HAT board is a companion board from that split, **not** a revision of the control board
- `hardware/control-board/` contains the working base-board source for the next redesign pass
- `hardware/control-board/archive/` keeps older control-board snapshots / backup exports for reference
- `hardware/hat-board/` contains the companion HAT-board source
- The solenoid-driver redesign direction is now centered on the **single-channel `TPS1H200A-Q1` smart high-side switch**

### Repo state
- New focused repo has been created to keep this work separate from the matrix board and other machine firmware
- Root-level upload clutter has been folded into the organized `hardware/` tree so the baseline stays clear
- The repo now contains project-local KiCad symbol / footprint / 3D-model support for `TPS1H200A-Q1`
- The repeated smart-switch channels are now in the control-board schematic
- A routed control-board PCB checkpoint now exists in `hardware/control-board/Pinball Control board.kicad_pcb`
- The main `TPS1H200A-Q1` footprint-library mismatch has now been corrected in both the schematic and PCB files

## Immediate next priorities
1. wait for delivery of the ordered Rev 1 PCB and BOM parts
2. use `docs/REV1_POWERUP_ON_ARRIVAL.md` as the arrival-session checklist
3. inspect received boards/parts and complete unpowered continuity checks first
4. perform first **current-limited 5 V only** bring-up before any real coil rail use
5. validate one smart-switch channel at a time and log CL/DELAY behavior

## Implementation checkpoint
- The project now has a concrete implementation note, a CL/DELAY bench-tuning table, a schematic conversion worksheet, a simple next-step bench plan, and a routed-board order checklist.
- The repo-local KiCad libraries for `TPS1H200A-Q1` are now present under `hardware/control-board/kicad-lib/`.
- The repeated `TPS1H200A-Q1` channels for the solenoid outputs are now in both the schematic and the routed PCB checkpoint.
- Rev 1 PCB and BOM orders are now placed; the project has moved into the delivery-and-bring-up stage.

## Open questions
- should the next revision keep the split **base board + HAT board** architecture, or fold more back into one board?
- is the best short-term solenoid workaround a `Vgs` clamp / gate-drive adjustment, or bypassing the on-board driver during development?
- what supporting firmware or connector documentation should move into this repo later?

## Firmware and bench checkpoint (2026-04-29)
### Confirmed this session
- Matrix/display board firmware upload on `COM4` completed successfully (`display_board` env).
- Control-board firmware upload on `COM5` completed successfully with serial boot confirmation.
- Firmware self-identification is now in boot logs:
	- `FW: <name> | build=<id> | sig=<hex> | built=<date time>`
- PlatformIO environment configuration now carries firmware ID macros and manual-boot-safe upload flags.
- Control-board switch logging now has suppression/rate-limiting summaries to reduce serial spam.
- TEST profile output exercise was validated on hardware with repeated output-test lines (`S2`..`S6`).

### Current practical state
- Control board can be flashed in either profile:
	- `captain_control_system` for normal integration behavior.
	- `captain_control_test` for active output cycling/bench proof-of-life.
- Matrix link can remain degraded while still running output test in TEST profile.
- Tomorrow's bench focus is to connect 5V for solenoid LEDs and validate playfield-light control path from control board.

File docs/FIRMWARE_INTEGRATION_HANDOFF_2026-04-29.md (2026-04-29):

# Firmware Integration Handoff — 2026-04-29

**Status**: Ready for Priority 1 Implementation  
**Handoff from**: Initial discovery and CI fix phase  
**Handoff to**: Firmware integration implementation  

---

## 1. Project Overview

This is a **migration of proven pinball machine behavior** across three hardware generations:
1. **Captain Fantastic home-edition** (original, proved core machine behavior + audio, but audio had switching noise under MOSFET drive)
2. **Control-board v1 PMOS redesign** (attempted to fix audio with higher voltage rails, but gate-drive stage exceeded Vgs limits; components damaged at 26V stress)
3. **New smart-switch boards** (current direction: TPS1H200A single-channel solenoid drivers + matrix board with VNQ7E100AJTR rows + LMV393 comparators + 74HC595 lamp columns)

**Core Goal**: Consolidate proven code from all three boards into one cohesive firmware set that runs on the new smart-switch hardware without reinventing already-solved behaviors (audio effects, matrix scanning, OTA firmware updates, I2C register protocols).

---

## 2. Current State Summary

### Control Board Firmware (~80% complete, structure-ready)
**Location**: `Captain-Fantastic-Control-and-Hat-Board/firmware/control-board/`  
**Framework**: Arduino, ESP32 dev kit, PlatformIO

| Component | Status | Notes |
|---|---|---|
| **main.cpp** | ✅ Scaffolded | FreeRTOS runtimes instantiated, loop structure correct, all subsystems wired |
| **I2C master polling** | ✅ Working | matrix_interface_runtime.cpp polls 0x24 every 20ms, link health tracking active |
| **Headbox 595 lamp drive** | ✅ Proven | Shift-register output for scoring display + attract mode, tested |
| **Solenoid GPIO config** | ✅ Locked | 5 channels (S2–S6 on GPIO 23, 19, 18, 5, 17), pulse timings defined |
| **Protocol contract** | ✅ Locked | HT16K33-style register model (0x00–0x07 lamps, 0x40–0x43 switches, 0xF0–0xF3 diag) |
| **Switch/lamp naming** | ✅ Complete | captain_mapping.h has all 32 switches + 40 lamps, GPIO bit lookups verified |
| **Game logic** | ❌ **STUB** | onMatrixSwitchEdge() callback is empty; no solenoid coupling, no scoring, no lamp state |
| **Audio system** | ⚠️ Infrastructure | MP3 queue + playback infrastructure present, not wired to game events |

**Key Files**:
- [src/main.cpp](../../firmware/control-board/src/main.cpp) — entry point, main loop
- [src/input/matrix_interface_runtime.cpp](../../firmware/control-board/src/input/matrix_interface_runtime.cpp) — I2C master to 0x24
- [src/headbox/headbox_runtime.cpp](../../firmware/control-board/src/headbox/headbox_runtime.cpp) — 595 lamp drive
- [include/captain_protocol.h](../../firmware/control-board/include/captain_protocol.h) — register map (LOCKED)
- [include/captain_mapping.h](../../firmware/control-board/include/captain_mapping.h) — switch/lamp names
- [include/solenoid_gpio_config.h](../../firmware/control-board/include/solenoid_gpio_config.h) — GPIO pin assignments

### Matrix Board Firmware (bring-up complete, **I2C slave missing**)
**Location**: `Pinball-Sw-Lamp-Matrix-/firmware/src/`  
**Framework**: ESP-IDF, ESP32-C6, native C++

| Component | Status | Notes |
|---|---|---|
| **Shift-register lamp drive** | ✅ Proven | sr_compose_frame() and sr_shift_frame() working, tested on hardware |
| **GPIO switch scan** | ✅ Proven | 5ms row advance, 8×4 matrix, per-row hit counters |
| **OLED debug display** | ✅ Working | Status telemetry, link activity bars |
| **I2C slave at 0x24** | ❌ **BLOCKER** | GPIO2/3 reserved in comments, not implemented; no i2c_slave.h, no register handlers |
| **Attract mode** | ✅ Proven | 24-step lamp sequence, 120ms cadence, ready for game logic |

**Key Files**:
- [src/main.cpp](../../Pinball-Sw-Lamp-Matrix-/firmware/src/main.cpp) — entry point, shift-reg + GPIO scan + OLED

### CI Build Status
**Status**: ✅ FIXED  
**Change**: Removed `platform_packages` line from platformio.ini (was pinning ESP-IDF version not resolvable on GitHub runners)  
**Verification**: GitHub Actions run 26+ should pass

---

## 3. Blocker Analysis & Priority Roadmap

### Priority 1 (BLOCKER): Add I2C Slave to Matrix Board
**Failure mode without this**: Control board cannot communicate with matrix board; matrix polling hangs; system initialization stalls.

**Implementation**:
- **File**: `Pinball-Sw-Lamp-Matrix-/firmware/src/main.cpp`
- **Scope**: 
  - Include `driver/i2c_slave.h`
  - Configure slave at address 0x24 on GPIO2 (SDA) / GPIO3 (SCL)
  - Implement register handlers for:
    - **0x00–0x07** (write-only): Lamp rows (8 bytes, one per row, bit=1 = lamp ON, active-high in register)
    - **0x40–0x43** (read-only): Switch snapshot (4 bytes, 32 switches packed, bit=1 = switch closure)
    - **0xF0–0xF3** (read-only): Diagnostics flags (system enabled, output enabled, test mode, live sample count)
  - Update register handler on every I2C write/read to stay in sync with real-time state
- **Acceptance**: 
  - Control board serial log shows `matrix detected = true`
  - Control board serial log shows `linkHealthy = true` (after 1 second)
  - Matrix board acknowledges write to 0x20 (system enable command) with register reflection

**Register Protocol (v1, Locked)**
```
Command writes:
  0x20 | 0x01  → Enable system (register 0xF0 bit 7 = 1)
  0x80 | 0x01  → Enable outputs (register 0xF0 bit 6 = 1)
  0xE0–0xEF    → Pulse level (0–15, used for diagnostic output pulse width)

Reads:
  0x00–0x07    → Lamp row state (mirror of last write)
  0x40–0x43    → Live switch snapshot (real-time scan result)
  0xF0         → System flags: bit7=sys_en, bit6=out_en, bit5–2=test_flags, bit1–0=diag_mode
```

---

### Priority 2: Implement Solenoid Coupling (Game Logic Entry Point)
**Blocker removed by**: Priority 1 (I2C slave working)  
**Dependency**: Matrix board responding to 0x24 reads; switch edges flowing through matrix_interface_runtime.cpp

**Implementation**:
- **File**: `Captain-Fantastic-Control-and-Hat-Board/firmware/control-board/src/main.cpp`
- **Location**: Search for `onMatrixSwitchEdge()` callback (currently empty stub)
- **Scope**:
  - Wire switch closures to solenoid pulses per machine rules:
    - Inlane switch (S1) → Inlane solenoid (S3)
    - Outlane switch (S20) → Outhole solenoid (S2)
    - Bumper switches → Bumper solenoid (S5) with optional multi-hit
    - Slingshot switches → Slingshot solenoids (S4 or S6)
  - Use `triggerSolenoid(SOLENOID_NAME)` from solenoid_gpio_config.h
  - Respect CAPTAIN_SOLENOID_PULSE_MS timing (45ms for S2/S3, 40ms for S4/S5/S6)
- **Acceptance**:
  - Physical switch press triggers audible solenoid click
  - Solenoid pulse lasts correct duration (verified on oscilloscope or by ear)
  - No double-triggers within 200ms (debounce window in matrix_interface_runtime.cpp)

---

### Priority 3: Scoring & Lamp State Machine
**Blocker removed by**: Priority 2 (solenoid coupling working; game events flowing)  

**Implementation**:
- **Scope**:
  - Track game state: score, player number, ball number, bonus multiplier
  - On solenoid trigger, increment score
  - Update lamp rows 0x00–0x07 on I2C write (score display, player indicator, ball indicator)
  - Update headbox 595 lamps (captain::headbox::Runtime already has setLamp/writeLamps)
- **Acceptance**:
  - Score increments on solenoid trigger
  - Lamp rows reflect score state on next I2C poll (20ms latency acceptable)

---

### Priority 4: Audio Parity Migration
**Dependency**: Priorities 1–3 working; game events flowing

**Implementation**:
- **Scope**:
  - Audio infrastructure (MP3 queue, playback) is already in control-board src/audio/
  - Wire solenoid trigger events to audio playback (bumper hit → bumper sound, etc.)
  - Migrate sound effects from home-edition or prior boards
- **Acceptance**:
  - Bumper hit triggers bumper sound effect without lag
  - No audio noise contamination on solenoid rail (validate with oscilloscope on 26V rail)

---

## 4. Technical Contracts & Locked Definitions

### I2C Register Map (Canonical)
| Address Range | Direction | Purpose | Notes |
|---|---|---|---|
| 0x00–0x07 | Write-only (control→matrix) | Lamp row state | 8 bytes, one per row; bit=1 ⇒ lamp ON (active-high) |
| 0x40–0x43 | Read-only (matrix→control) | Switch snapshot | 4 bytes packed; bit=1 ⇒ switch closure (active-high) |
| 0xF0–0xF3 | Read-only (matrix→control) | Diagnostics flags | System enable, output enable, test flags, live sample counts |
| 0x20, 0x80, 0xE0–0xEF | Command (control→matrix) | System control | Enable sys, enable outputs, set pulse levels |

**I2C Parameters**:
- Slave address: **0x24**
- GPIO (matrix board): **GPIO2 (SDA), GPIO3 (SCL)**
- GPIO (control board): **GPIO21 (SDA), GPIO22 (SCL)** (main I2C bus, shared with OLED)
- Frequency: **100 kHz**
- Poll interval (control→matrix): **20 ms**
- Link timeout: **1000 ms** (if no heartbeat in 1s, linkHealthy = false)

### Hardware Configuration

#### Control Board
- **MCU**: ESP32 (dev kit), Arduino framework, PlatformIO
- **Solenoid pins** (TPS1H200A drivers, 5 channels):
  - S2 (Outhole): GPIO23, 45ms pulse
  - S3 (Inlane): GPIO19, 45ms pulse
  - S4 (Slingshot): GPIO18, 40ms pulse
  - S5 (Bumper): GPIO5, 40ms pulse
  - S6 (Slingshot): GPIO17, 40ms pulse
- **Headbox lamps** (595 shift-register):
  - DATA: GPIO14, CLOCK: GPIO27, LATCH: GPIO26, OE_N: GPIO12
  - Scoring display + attract mode
- **OLED**: GPIO21/22 (I2C main bus)
- **Power rails**:
  - 5V logic
  - 3.3V for ESP32
  - 18V for lamp matrix (separate)
  - 22–26V for solenoids (separate, high-side switch input to TPS1H200A)

#### Matrix Board
- **MCU**: ESP32-C6, ESP-IDF framework
- **Lamp matrix**: 8×4 (28 lamps), 6.3V incandescent
  - Shift-register pins: GPIO15 (DATA), GPIO22 (CLK), GPIO23 (LATCH), GPIO10 (OE_N)
  - Row drivers: VNQ7E100AJTR (quad, active-high outputs)
  - Column inputs: GPIO18–21 (SW_COL_0–3), active-low
- **Switch matrix**: 8×4 (32 switches)
  - Row advance: 5ms cadence, full cycle = 40ms
  - Edge detection + debounce at matrix_interface_runtime.cpp (20ms window)
- **I2C** (to be implemented):
  - Slave at 0x24 on GPIO2 (SDA) / GPIO3 (SCL)
  - **TODO**: Configure in main.cpp
- **OLED**: GPIO6/7 (separate I2C master for status display)
- **Power**: 5V logic, 3.3V for ESP32-C6, 6.3V for lamps (separate rails)

### Switch & Lamp Naming (captain_mapping.h, Locked)
**32 Switches (8×4 matrix)**:
- S20 Outhole, S1 Lane A, S2 Lane B, S3 Lane C, S4 Lane D, S5 Tilt, S6 Outlane Left, S7 Outlane Right
- S10 Inlane Left, S11 Inlane Right, Bumper A, Bumper B, Bumper C, Bumper D, Slingshot L, Slingshot R
- (8 more spare rows reserved)

**40 Lamps (8×5 matrix)**:
- Game Over, Lanes A/B/C/D, Bumper indicators, Bonus display, Player indicators, Ball indicators
- (Remaining slots for future)

---

## 5. Code Archaeology: What Exists & What's Reusable

### High-Confidence Reusable Modules

**Shift-Register Frame Composition** (`matrix main.cpp: sr_compose_frame()`)
```cpp
uint16_t sr_compose_frame(uint8_t rowByte, uint8_t colByte) {
  // Applies active-low inversion if needed
  // Daisy-chain order: U5 (columns) first, U4 (rows) second
  // Returns 16-bit frame ready for sr_shift_frame()
}
```
**Status**: Proven on matrix hardware, should be copied to control-board HAT driver if needed.

**I2C Master Register Read Pattern** (`matrix_interface_runtime.cpp: readRegisterBlock()`)
```cpp
bool readRegisterBlock(uint8_t regStart, uint8_t* pBuf, size_t count) {
  Wire.beginTransmission(0x24);
  Wire.write(regStart);
  Wire.endTransmission(false);
  Wire.requestFrom(0x24, count, true);
  for (size_t i = 0; i < count && Wire.available(); i++) {
    pBuf[i] = Wire.read();
  }
}
```
**Status**: Working, verified against matrix board; use as template for any other I2C master patterns.

**Switch Edge Emission** (`matrix_interface_runtime.cpp: emitSwitchEdges()`)
- Compares previous/current switch bytes
- Calls user callback for each edge transition
- **Pattern**: Proven debounce + edge logic, reuse for any button/switch polling

**Headbox Lamp Attract Pattern** (`headbox_runtime.cpp: attractPattern()`)
- Chases lamps in sequence (24-step pattern defined in captain_mapping.h)
- Ready to adapt for ROM-driven gameplay
- **Status**: Proven, tested

**FreeRTOS Task Structure** (both boards)
- Both control and matrix boards use FreeRTOS with multiple tasks
- Proven pattern: separate tasks for I/O polling, display updates, time-critical solenoid pulses
- Ready to extend for scoring, audio queuing

### Historical Code Available (Not Yet Migrated)

**Home-Edition Behavior** (if needed for reference):
- Audio effects queue system (potentially in home-edition repo)
- OTA two-stage system (control-board infrastructure present)
- Sound effects ROM (if available, can be ported)

---

## 6. Testing & Validation Checklist

### Pre-Integration (Unit-level)
- [ ] Matrix board I2C slave responds to reads at 0x24 (use I2C scanner or control-board probe)
- [ ] Matrix board shift-register lamp updates visible on hardware
- [ ] Control board GPIO solenoid outputs toggle correctly (verify with multimeter or oscilloscope)

### Integration (System-level)
- [ ] Control board serial log shows `matrix detected = true`
- [ ] Control board serial log shows `linkHealthy = true` (within 1s of startup)
- [ ] Control board can write lamp rows; matrix board reflects on shift-register output
- [ ] Control board can read switch state; matrix board reports correct closures
- [ ] Physical switch press → solenoid pulse triggers (audible click + GPIO toggle)

### Audio Validation (When Audio Wired)
- [ ] Solenoid trigger event plays audio effect
- [ ] No switching noise on 26V solenoid rail (oscilloscope check: <100mV ripple at 20MHz bandwidth)

---

## 7. File Structure & Key Locations

```
Captain-Fantastic-Control-and-Hat-Board/
├── firmware/
│   └── control-board/
│       ├── src/
│       │   ├── main.cpp                      ← Game loop, callback stub at onMatrixSwitchEdge()
│       │   ├── input/
│       │   │   └── matrix_interface_runtime.cpp  ← I2C master polling 0x24
│       │   ├── headbox/
│       │   │   └── headbox_runtime.cpp       ← 595 lamp drive
│       │   ├── audio/
│       │   │   └── audio_runtime.cpp         ← Audio infrastructure
│       │   └── ota/
│       ├── include/
│       │   ├── captain_protocol.h            ← Register map (LOCKED)
│       │   ├── captain_mapping.h             ← Switch/lamp names (LOCKED)
│       │   ├── solenoid_gpio_config.h        ← GPIO assignments (LOCKED)
│       │   └── i2c_bus_config.h              ← I2C bus config (0x24 slave addr)
│       └── platformio.ini                    ← Build config (FIXED: removed version pin)

Pinball-Sw-Lamp-Matrix-/
├── firmware/
│   └── src/
│       ├── main.cpp                          ← **TODO: Add I2C slave at 0x24**
│       └── CMakeLists.txt
```

---

## 8. Next Developer Handoff Instructions

### Setup
1. Clone both repositories:
   ```
   C:\cfhe\Pinball-Sw-Lamp-Matrix\firmware\ (no spaces, ESP-IDF requirement)
   Captain-Fantastic-Control-and-Hat-Board/firmware/control-board/
   ```
2. Install dependencies:
   - PlatformIO + ESP32 toolchain (control board)
   - ESP-IDF + ESP32-C6 toolchain (matrix board)
3. Verify CI build passes (GitHub Actions run 26+)

### Immediate Action
**Start with Priority 1**: Implement I2C slave at 0x24 on matrix board
- Follow the register protocol in Section 4
- Use `driver/i2c_slave.h` as reference
- Test with control-board I2C master polling (20ms interval)

### Success Criteria for Each Priority
- **Priority 1**: `linkHealthy = true` in control-board serial log
- **Priority 2**: Solenoid pulse triggered by physical switch press
- **Priority 3**: Score increments, lamps update
- **Priority 4**: Audio plays on solenoid event, no noise on power rail

### Documentation Updates
- [ ] Update PROJECT_STATUS.md when Priority 1 is complete
- [ ] Update FIRMWARE_MIGRATION.md when Priority 2 is complete
- [ ] Create AUDIO_MIGRATION_NOTES.md when starting Priority 4

---

## 9. Known Issues & Gotchas

| Issue | Impact | Workaround | Status |
|---|---|---|---|
| platformio.ini pinned ESP-IDF version | CI build failure | Removed platform_packages line | ✅ Fixed |
| Matrix board no I2C slave | Integration blocked, system won't init | Implement Priority 1 | ⏳ Pending |
| Control-board onMatrixSwitchEdge() empty | No solenoid coupling | Implement Priority 2 | ⏳ Pending |
| Audio not wired to game events | Audio doesn't play | Wire Priority 4 | ⏳ Pending |

---

## 10. Contact Points & References

**Original Discovery**: This handoff document was compiled from:
- Full codebase audit of both repos (control-board and matrix-board)
- GPIO assignments verified in solenoid_gpio_config.h and captain_mapping.h
- Register protocol locked in captain_protocol.h and validated across both boards
- I2C master polling verified working in matrix_interface_runtime.cpp

**Previous Commits**:
- **CI fix**: Removed platformio.ini `platform_packages` line (run 26 pending)
- **Last working matrix board state**: Standalone shift-register + GPIO scan operational
- **Last working control board state**: I2C master polling enabled, awaiting I2C slave response

**Architecture Decision Log**:
- Chose HT16K33-style I2C register model for simplicity and proven track record
- Chose TPS1H200A for solenoid drivers (single-channel, simple GPIO interface, safe gate drive)
- Chose ESP32-C6 for matrix board (native I2C slave support, strong PWM capabilities)

---

**Last Updated**: 2026-04-29  
**Next Review**: After Priority 1 completion  
**Owner**: Next Developer (take over from here)

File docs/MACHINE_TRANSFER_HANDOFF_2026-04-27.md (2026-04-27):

# Machine Transfer Handoff (2026-04-27)

Purpose: continue matrix-board bring-up work from a different development station without losing current direction.

## Session Summary
- We confirmed this local workspace is the control-board/HAT repo, not the active matrix hardware repo.
- You confirmed the active target is the separate matrix repo:
  - https://github.com/Phil-CIA/Pinball-Sw-Lamp-Matrix-
- We pulled the current matrix repo status from remote docs and aligned to the current bench stage:
  - board state = assembled, not powered yet
  - project phase = first bring-up / hardware validation

## Matrix Repo Status Snapshot (for restart)
- Architecture baseline remains:
  - 8x4 lamp matrix driver + 8x4 switch scanner
  - VNQ7E100AJTR high-side row drivers
  - LMV393 comparator switch readback
  - 74HC595 output expansion
  - ESP32-C6 firmware bring-up scaffold (ESP-IDF via PlatformIO)
- Documented project state indicates Rev 1 hardware ordering and bring-up-prep workflow.
- Bring-up docs already define staged flow:
  - visual inspection
  - continuity checks (18V/5V/3.3V to GND)
  - current-limited first power
  - logic validation
  - one-row/one-column lamp validation before full scan

## Agreed Restart Point
- Latest matrix board is assembled and unpowered.
- Immediate objective: safe first power-up and logic-path validation before broad lamp stress testing.

## Execution Plan on Dev Station
1. Session prep and stop conditions
   - Bench supply current limit set before power.
   - DMM + scope/logic probe ready.
   - Hard stop rules defined (overcurrent, wrong rail, unusual heating/smell).

2. Unpowered checks
   - Visual inspection (orientation, solder defects, connector pin 1).
   - Rail continuity/short checks:
     - 18V to GND
     - 5V to GND
     - 3.3V to GND
   - Verify no accidental coupling from lamp rail into logic rails.

3. First power-up (current-limited)
   - Bring up supply conservatively.
   - Verify 5V rail first, then 3.3V logic rail.
   - Confirm no abnormal heating on power/protection/driver areas.

4. Firmware/logic smoke test
   - Run existing ESP32-C6 bring-up firmware.
   - Verify boot output.
   - Probe shift-register lines: SR_SCLK, SR_LATCH, SR_DATA0.
   - Validate switch-column readback behavior: SW_COL_0..SW_COL_3.

5. Boot safety checks
   - Verify /OE and /MR behavior is safe at startup.
   - Confirm no unintended lamp flash at boot.

6. Staged lamp-path validation
   - Test one row + one column first.
   - Expand to supervised full scan only after first pass is stable.
   - Watch connector temperature, supply sag, and thermal hotspots.

7. Capture findings immediately
   - Log rail values, current draw, thermal observations, and mapping/polarity notes.
   - Update matrix repo docs with findings before ending session.

## Files To Use First (matrix repo)
- README.md
- docs/PROJECT_STATUS.md
- docs/BRINGUP_CHECKLIST.md
- docs/NEXT_ITERATION.md
- docs/PINMAP.md
- firmware/src/main.cpp

## Suggested First Prompt on Dev Station
"Resuming matrix-board bring-up on assembled unpowered Rev 1 hardware. Use docs/BRINGUP_CHECKLIST.md and docs/NEXT_ITERATION.md as primary flow. Execute staged checks: unpowered continuity, current-limited first power, logic probe of SR_SCLK/SR_LATCH/SR_DATA0 and SW_COL_0..SW_COL_3, then one-row/one-column lamp test before full scan. Record pass/fail and measured values after each phase."

## Scope Reminder
- This handoff captures matrix-board bring-up direction only.
- Control-board/HAT repo changes were not the target for this restart session.

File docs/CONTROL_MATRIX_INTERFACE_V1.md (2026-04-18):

# Control ↔ Matrix Board Interface Contract (v1)

**Status:** Locked as the intended stable control-to-matrix behavior contract  
**Last Updated:** 2026-04-18  
**Purpose:** Define how the control board should treat the matrix board for MVP integration.

This document intentionally keeps the **HT16K33-style operating concept** for the split-board system. The point is not to let the control board micromanage matrix timing; the point is to give the control board a simple, durable peripheral model while the matrix-board firmware stays free to change internally whenever needed.

**Important framing:**
- this is the **preferred inter-board behavior contract**
- the matrix board may still use local GPIO, shift registers, and bring-up-only firmware details under the hood
- those local implementation details do **not** require abandoning the simple external HT16K33-style model

---

## 1. Board Ownership Boundary

### Control board owns
- game state machine
- scoring and bonus logic
- audio behavior
- diagnostics policy
- persistence and operator settings
- lamp intent decisions
- system-level fault handling policy

### Matrix board owns
- switch matrix scanning
- switch debounce and stable-state publication
- lamp multiplex timing and low-level drive execution
- boot-safe output behavior
- local implementation details needed to satisfy the external contract

### Explicit non-goals for v1
- the control board does **not** tune scan rate, debounce policy, or row/column service sequencing during normal play
- the matrix board does **not** own gameplay rules, scoring rules, or feature progression

---

## 2. Preferred v1 Contract Model

- **Bus:** I2C
- **Role split:** control board = master, matrix board = slave/peripheral
- **Preferred slave address:** **0x24**
- **Wire model:** HT16K33-style command plus register-pointer interface
- **Master pattern:** write simple global commands directly, write a register pointer then payload for lamp image updates, and read stable switch/diagnostic snapshots by pointer + repeated-start read

### Implementation-freedom note
The matrix firmware is free to implement this behavior using whatever internal method is most practical, including local GPIO control, shift-register expansion, local scan loops, or later firmware refactors. That internal method is **not** the control-board contract.

There is **no required framed packet protocol** in current v1.

---

## 3. Canonical v1 Data Structures

### 3.1 Lamp image written by control board

```c
uint8_t lampRows[8];
```

- register window: **0x00..0x07**
- one byte per row
- lower **4 bits** are active lamp columns for that row
- upper 4 bits are reserved and must be written as 0
- the matrix board retains the last valid lamp image until it is overwritten or outputs are disabled

### 3.2 Switch snapshot read by control board

```c
uint8_t switchBytes[4];
```

- register window: **0x40..0x43**
- packed representation of the **8 x 4** switch matrix
- each bit represents the latest debounced stable state for one switch position
- **bit value 1 = switch closed / active**
- control logic should compare the newest snapshot against the previous snapshot to detect new closures

### 3.3 Diagnostic snapshot

```c
typedef struct {
  uint8_t statusFlags;
  uint8_t pulseLevel;
  uint8_t lampSample;
  uint8_t switchSample;
} MatrixDiagV1;
```

- register window: **0xF0..0xF3**
- current agreed meanings:
  - **0xF0** = status flags
    - bit 0 = system enabled
    - bit 1 = output enabled
    - bit 2 = test override active
    - bit 3 = auto-walk active
  - **0xF1** = current pulse-width level, 0..15
  - **0xF2** = live echo/sample of lamp row 0
  - **0xF3** = live echo/sample of switch byte 0

### 3.4 Matrix-local runtime state

The matrix board keeps these as internal state variables:
- system enabled or disabled
- output enabled or disabled
- lamp pulse-width level, 0..15
- latest retained lamp-row image
- latest debounced switch snapshot

---

## 4. Minimal v1 Instruction Set

### 4.1 Global command bytes

| Command | Meaning | Expected effect |
|---:|---|---|
| **0x20** | System disable | stop active matrix service behavior and force safe inactive state |
| **0x21** | System enable | enable normal matrix scanning and runtime operation |
| **0x80** | Output disable | disable lamp outputs while keeping configuration state |
| **0x81** | Output enable | allow lamp output using the retained lamp image |
| **0xE0..0xEF** | Set pulse-width level | update the global lamp pulse-width level using the low nibble |

### 4.2 Register windows

| Address range | Direction | Meaning |
|---|---|---|
| **0x00..0x07** | write | lamp row image |
| **0x40..0x43** | read | switch snapshot bytes |
| **0xF0..0xF3** | read | diagnostics/status |

### 4.3 v1 transaction rules

- lamp updates are sent as a block write beginning at **0x00**
- switch reads are done as a block read beginning at **0x40**
- diagnostics reads are done beginning at **0xF0**
- there is **no commit register** in current v1
- there is **no explicit ready/heartbeat register** in current v1
- there is **no change-mask or event FIFO** in current v1
- the control board sends **intent**, not low-level scan-engine configuration

---

## 5. Timing Contract

### Matrix board internal timing
- main service loop target: **5 ms**
- scan/debounce target: **20 ms** stable debounce window
- one gameplay closure should only be reported once until that switch is released again
- lamp application latency target after a valid write: **within the next normal scan cycle**

### Control board polling and update timing
- switch polling target during active play: **every 10 to 20 ms**
- diagnostic polling target: **every 100 to 250 ms**, or on fault suspicion
- lamp writes: **on gameplay or mode changes**, with optional periodic refresh at **100 to 250 ms**
- control board should **not** spam lamp writes every matrix scan cycle

### Link supervision rule for MVP
- v1 uses **transaction success and diagnostics readability** as the health check
- if the control board cannot complete successful matrix transactions for about **1000 ms**, it should treat the matrix link as failed
- on link failure, the machine should fall back to the existing safe policy: inhibit gameplay continuation and avoid destructive output behavior

---

## 6. Control-Side Interpretation Rules

- the control board treats the **latest valid debounced switch snapshot** as authoritative
- duplicate or repeated reads of the same active bit are harmless and ignored idempotently
- release events do not need a separate wire-level event message in v1; they are inferred by comparing successive snapshots
- scoring logic fires from **new closures**, not from a held switch remaining active across multiple polls

---

## 7. Safe-State Rules

- if system is disabled, the matrix board must not actively drive the lamp matrix
- if output is disabled, lamp outputs remain off even if lamp row RAM is nonzero
- invalid or unsupported future protocol ideas must not disturb the last known safe runtime state in v1
- the matrix board remains timing-focused and should avoid embedding higher-level game logic

---

## 8. Current Bench-Implementation Note

The up-to-date matrix-board repo may still use direct local firmware routines, GPIO activity, and shift-register hardware during bring-up. That is acceptable and expected during bench validation.

The important architectural point is this:
- **implementation can evolve freely**
- **the control-side contract should stay simple**
- **HT16K33-style behavior is still the preferred abstraction**

---

## 9. Recommended Bring-Up / Alignment Order

1. verify safe power-up and boot behavior on the matrix board
2. validate the local scan/multiplex firmware on the bench
3. align the shared firmware to the agreed `0x24` behavior contract
4. write known patterns into **0x00..0x07** and verify lamp mapping
5. read **0x40..0x43** while actuating switches and confirm closures map correctly
6. read **0xF0..0xF3** and confirm status and pulse level
7. tune row/column polarity or mapping only after the contract above is verified

---

## 10. Lock Summary

For the preferred first aligned split-board firmware:
- **behavior contract = HT16K33-style I2C peripheral model**
- **control board responsibility = send lamp intent and read stable switch/diagnostic state**
- **matrix board responsibility = own the low-level implementation and timing details**

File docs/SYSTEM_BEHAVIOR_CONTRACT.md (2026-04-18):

# System Behavior Contract — Captain Fantastic Control Board Firmware

This top-level copy mirrors the firmware-level contract at:
- firmware/control-board/docs/SYSTEM_BEHAVIOR_CONTRACT.md

Use this document to lock architecture and behavior decisions before implementation.

## System Partition Note

This contract now reflects the current multi-board split:
- the matrix board owns switch scanning, debounce, and lamp-drive timing
- the control board owns game state, scoring, audio, diagnostics, display behavior, and high-level output policy
- the control board should consume debounced events and send high-level lamp intent rather than directly multiplex the lamp or switch matrix
- the intended MVP inter-board behavior contract is locked in docs/CONTROL_MATRIX_INTERFACE_V1.md and keeps the simple HT16K33-style peripheral model as the preferred abstraction, even if the matrix firmware changes internally during bring-up

**Status:** User answers integrated
**Last Updated:** 2026-04-17
**Owner:** [You]
**Reference Sources:**
- Captain-Fantastic-home-edition/src/main_firmware.cpp (lines 105-1143: game state machine, scoring, bonus, diagnostics)
- Captain-Fantastic-home-edition/docs/MP3_MUSIC_SETUP.md (audio architecture intent)
- Captain-Fantastic-home-edition/docs/WIFI_STREAMING_SETUP.md (hybrid storage/streaming model)
- Captain-Fantastic-home-edition/docs/DIAGNOSTIC_TEST_MODE.md (Bally diagnostic specification)

---

## I. GAME STATE MACHINE

**Authoritative Source:** main_firmware.cpp lines 1024-1143

### Six States (50ms cycle interval)
1. ATTRACT - Idle loop, random lamp chase, attract music, awaiting START button
2. GAME_START - Player pressed START, play start fanfare, initialize scoring/bonus/multiplier
3. BALL_IN_PLAY - Active gameplay, switches score points, solenoids respond, lamps track features
4. BONUS_COUNTDOWN - Ball drained, count down bonus to score, play countdown music
5. BALL_OVER - End of bonus countdown, return to ATTRACT
6. GAME_OVER - All balls exhausted, play game-over fanfare, flash high-score lamps

### State Transitions
```
ATTRACT --[START button]--> GAME_START
GAME_START --[immediate]--> BALL_IN_PLAY
BALL_IN_PLAY --[drain/tilt]--> BONUS_COUNTDOWN
BONUS_COUNTDOWN --[countdown ends]--> BALL_OVER
BALL_OVER --[immediate OR new ball time]--> BALL_IN_PLAY (repeat) OR GAME_OVER (if no balls left)
GAME_OVER --[display high score]--> ATTRACT
```

---

## II. SCORING AND SWITCH MATRIX (22 Switches)

**Authoritative Source:** main_firmware.cpp lines 620-754

### Switch Functions and Point Values

| Switch | Point Value | Solenoid Coupling | Feature Logic |
|---|---|---|---|
| Bumper 1 | 100 | None | Kickback ready if lit |
| Bumper 2 | 100 | None | Kickback ready if lit |
| Bumper 3 | 100 | None | Kickback ready if lit |
| Lane A | 500 | None | Lane complete tracking -> Extra ball at A-B-C-D |
| Lane B | 500 | None | Lane complete tracking |
| Lane C | 500 | None | Lane complete tracking |
| Lane D (Return Left) | 1000 | Multiplier advance | Advance return lane 1X->2X->3X->5X on successive completions |
| Lane E (Return Right) | 1000 | Multiplier advance | Advance return lane multiplier |
| Target 1 | 250 | Solenoid-1 | Target progression 1-2-3 -> Double/Triple bonus at 3-complete |
| Target 2 | 250 | Solenoid-2 | Target progression |
| Target 3 | 250 | Solenoid-3 | Target progression |
| Rollover 1 | 300 | None | Bonus pole increment (1K-19K) |
| Rollover 2 | 300 | None | Bonus pole increment |
| Rollover 3 | 300 | None | Bonus pole increment |
| Spinner | 750 | None | Bonus multiplier advance or score |
| Jet Bumper | 50 | Solenoid-4 | Rapid drain risk, eject on hit |
| Ramp 1 (Start) | 1000 | None | Ramp combo tracking |
| Ramp 2 (Mid) | 2000 | None | Ramp combo tracking |
| Ramp 3 (End) | 5000 | Solenoid-5 | Ramp complete -> Feature lit or bonus advance |
| Slingshot Left | 10 | Multiplier advance | Advance slingshot multiplier on hit |
| Slingshot Right | 10 | Multiplier advance | Advance slingshot multiplier on hit |
| Tilt | 0 | Tilt solenoid | End ball immediately, disable flipper, drain ball fast |

### Ball Count and Extra Ball Policy
- Standard game uses 5 balls
- Extra ball awards do not decrement the current ball counter
- When an extra ball is awarded, the player stays on the current ball
- Software does not cap extra balls in the first pass

### Extra Ball Awards
- 100K points -> Extra ball light
- 200K points -> Extra ball light
- 300K points -> Extra ball light

### Bonus Pole (Displayed as 1K-19K)
- Incremented by Rollover switches (each +1K)
- Initial countdown trial: 750 ms per scoring step
- Play a bonus sound on every step
- Countdown can accelerate as a tuning trial after the initial slower cadence
- Multiplied by Return Lane multiplier (1X, 2X, 3X, or 5X)

---

## III. AUDIO ARCHITECTURE

**Authoritative Sources:**
- main_firmware.cpp lines 301-341 (sound effect enums, music track enums)
- main_firmware.cpp lines 1300-1435 (audio function definitions)
- MP3_MUSIC_SETUP.md (intended storage and policy)

### Sound Effects (13 Types)
1. Bumper hit (700 Hz, 50ms)
2. Slingshot (rising tone 400->900 Hz, 100ms)
3. Target hit (1300 Hz, 80ms)
4. Rollover (bell tone, 200ms)
5. Ball drain (descending 1000->200 Hz, 300ms)
6. Bonus counting (1000 Hz, rapid pulses 100ms each)
7. Feature lit (fanfare 2-note melody)
8. Extra ball (descending fanfare)
9. Startup tone (system boot confirmation)
10. Game start (game-start fanfare, ~2-3s)
11. Game over (game-over fanfare, ~2-3s)
12. Tilt (harsh buzzer, 500ms)
13. Switch open/close debug (low tone debug alert)

### Music Tracks (5 Roles)

| Track Role | Filename | Duration | Loop Policy | Volume |
|---|---|---|---|---|
| Attract | /attract.mp3 | 3-5 min | Loop indefinitely | 0.3-0.4 (background) |
| Game Start | /game_start.mp3 | 1-3 sec | Play once | 0.8 (prominent) |
| Bonus Countdown | /bonus.mp3 | 20 sec | Play once | 0.6-0.7 |
| Game Over | /game_over.mp3 | 2-3 sec | Play once | 0.8 (prominent) |
| High Score | /hiscore.mp3 | 3-5 sec | Play once | 0.8 (prominent) |

#### Legacy Implementation Status
- Music functions defined: requestMusic(), playMusic(), updateMusicPlayer()
- Audio event matrix defined (game state -> music trigger mapping)
- NOT implemented: Music functions never called from game state machine in current main_firmware.cpp
- NOT implemented: Audio task explicitly disables MP3 playback ("MP3 playback disabled - sound effects only")

---

## IV. STORAGE BUDGET MODEL

**Calculation Basis:** ESP32 app partition ~1.31MB; W25Q128 external flash 16MB

| Component | Size | Notes |
|---|---|---|
| Firmware binary | ~1.12 MB | Current code with all subsystems |
| OTA staging reserve | ~2.0 MB | Conservative; covers max firmware + overhead |
| Usable audio library | ~14 MB | Remaining for MP3 assets on W25Q128 |

### Audio Capacity (W25Q128 14MB)
- At 128 kbps: ~14-15 minutes total content
- At 96 kbps: ~19-20 minutes total content
- Recommended: Attract (3min) + 4 game tracks (30s each) = ~5 min total; leaves 9-15 min for future expansion

### Secondary Storage (SPIFFS Internal Flash)
- ~1.9 MB usable for bootstrap/fallback files
- Use for: Short sound cues, startup test tone, fallback attract track if WiFi fails

---

## V. DIAGNOSTIC SYSTEM (Bally Series II)

**Authoritative Source:** DIAGNOSTIC_TEST_MODE.md, main_firmware.cpp lines 930-1143

### Five-Step Diagnostic Sequence

#### Step 1: Logic/Program Test
- Display "600d" on 7-segment
- Duration: 3 seconds
- Purpose: Confirm CPU can reach diagnostics code

#### Step 2: Score Display Scan
- Increment display 0 -> 999999 by 111 each cycle
- Duration: ~90 seconds (cycles until test button released)
- Purpose: Verify all segment drivers and multiplexing

#### Step 3: Lamp Test
- Alternate between two groups (GROUP 1 and GROUP 2)
- GROUP 1: Bumpers, Targets, Returns, extra-ball lamps
- GROUP 2: Lanes, Spinners, Ramps, feature lamps
- 5 cycles each group, ~10 seconds total
- Purpose: Verify all lamp matrix output drivers

#### Step 4: Solenoid Test
- Fire solenoids sequentially: 0 (kickback) -> 1 (target 1) -> 2 (target 2) -> 3 (target 3) -> 4 (ramp eject)
- 1 second pulse each
- Duration: ~5 seconds total
- Purpose: Verify all solenoid driver circuits and coil continuity

#### Step 5: Switch Stuck Detection
- Poll all 22 switches for stuckness (constant press without release)
- Error code format: (Row x 10) + Column
  - Example: Row 2, Col 3 -> Error code 23
- Duration: Continuous until test button released
- Purpose: Catch stuck/shorted switch inputs before game starts

---

## VI. STARTING DESIGN DECISIONS — INITIAL DEFAULTS

These are the first decisions to unblock implementation. More decisions will likely be added as bring-up continues, but the defaults below give the project a clean starting direction.

### DECISION 1: Audio Storage Model

**Question:** How should the firmware handle audio file storage and playback?

**Options:**
- A) Local-Only (W25Q128): All 5 MP3 tracks stored on external flash; no network dependency
- B) Hybrid (Local + WiFi Streaming): Attract mode streams unlimited songs from music_server.py on PC (LAN fallback to 1-2 pre-loaded tracks on W25Q128)
- C) Defer Streaming: Local-only now; WiFi streaming as future feature after core gameplay stabilizes

**Decision:**
```
[ ] A) Local-Only
[ ] B) Hybrid Local + WiFi Streaming
[x] C) Defer Streaming
```

**Reasoning (starting default):**
```
Bring-up first. Keep playback local and remove WiFi or PC-server dependency until core game-state audio is proven stable.
```

---

### DECISION 2: Music Playback Policy

**Question:** Which game events should trigger music, and which events can interrupt?

**Options:**
- A) Attract-Mode Only: Full-song MP3 loops only during ATTRACT; no in-game background tracks
- B) Event-Triggered Full Immersion: Start event -> game-start fanfare; during BALL_IN_PLAY -> continuous dynamic background; Bonus -> bonus countdown music; Game Over -> game-over fanfare
- C) Hybrid: Attract full songs + Game Start/Game Over/Bonus events, but no continuous background during play

**Decision:**
```
Playback Scope: [ ] A) Attract-Only  [ ] B) Full Immersion  [x] C) Hybrid Events
Interrupt on Tilt: [x] Yes  [ ] No
Interrupt on Drain: [x] Yes  [ ] No
```

**Reasoning (locked answer):**
```
Yes to all listed event-triggered audio hooks for the MVP set: attract, start, bonus, and game-over event playback are enabled, while continuous in-play background music stays off for now.
```

---

### DECISION 3: Canonical Game Logic Source

**Question:** Which legacy code repository should be the authoritative source for game scoring, state machine, and bonus logic during control-board migration?

**Current Status:**
- Authoritative: Captain-Fantastic-home-edition/src/main_firmware.cpp (fully tested, complete game parity)
- Reference Only: Captain-Fantastic-Control-and-Hat-Board/.../legacy_control_main.cpp (hardware validation, not full gameplay parity)

**Decision:**
```
Use home-edition main_firmware.cpp as authoritative source: [x] Agree  [ ] Discuss Further

If discussing further, please note concerns:
None at this time.
```

---

### DECISION 4: Diagnostic Parity Timeline

**Question:** Should the firmware implement the full Bally Series II diagnostic sequence immediately, or phase it after core gameplay/audio?

**Options:**
- A) Now (Full Parity): Implement all 5 diagnostic steps immediately
- B) Phased: Core diagnostics now (logic test + display scan), defer solenoid/switch tests until core gameplay stabilizes
- C) Minimal: Only logic test + display scan now; full sequence as maintenance feature after v1.0 stable

**Decision:**
```
Timeline: [ ] A) Now (Full Parity)  [x] B) Phased (2 weeks)  [ ] C) Minimal v1.0
```

**Reasoning (starting default):**
```
Bring up the core game loop and audio behavior first, while still keeping early diagnostic coverage for logic and display validation.
```

---

## VII. NEXT DECISION SET — TIMING AND SAFETY DEFAULTS

These are the next starting defaults to support reliable bench bring-up.

### DECISION 5: Matrix-Board Switch Event Contract

**Question:** What should the matrix board report to the control board for switch activity during the first playable firmware?

**Options:**
- A) Conservative: 10 ms scan with 30 ms debounce before reporting events
- B) Balanced: 5 ms scan with 20 ms debounce and one event per closure
- C) Fast: 2 ms scan with 10 to 15 ms debounce and faster event delivery

**Decision:**
```
Matrix-board scan interval: [ ] A) 10 ms  [x] B) 5 ms  [ ] C) 2 ms
Matrix-board debounce window: [ ] 30 ms  [x] 20 ms  [ ] 10 to 15 ms
Reported edge behavior: [x] One score event per closure until release
Control-board role: [x] Consume debounced events only
```

**Reasoning (starting default):**
```
The responsiveness target stays the same, but the ownership is now on the matrix board. The control board should receive clean switch events rather than raw matrix timing.
```

---

### DECISION 6: Solenoid Safety and Pulse Policy

**Question:** What safety limits should be applied to gameplay solenoids during early bring-up?

**Options:**
- A) Strict protection: short pulse, single-coil behavior, and conservative lockout
- B) Balanced protection: 50 ms pulse width, 50 ms cooldown, and up to 2 concurrent coils
- C) Permissive bring-up: looser software limits for faster experimentation

**Decision:**
```
Pulse cap default: [ ] A) short  [x] B) 50 ms  [ ] C) Loose and tune later
Retrigger cooldown: [ ] 125 ms  [x] 50 ms  [ ] Disabled
Maximum concurrent gameplay coils: [ ] 1  [x] 2  [ ] Unlimited
Disable on tilt or fault: [x] Yes  [ ] No
```

**Reasoning (locked answer):**
```
Use the requested 50 ms pulse width, 50 ms cooldown, and 2-coil concurrency as the starting gameplay trial, while still keeping hard fault and tilt suppression enabled.
```

**Safety rules:**
- A solenoid may not re-fire while it is already active unless the cooldown has elapsed
- A hard timeout always wins over gameplay requests
- Tilt or fault states immediately suppress gameplay solenoid firing
- Per-coil tuning can be added later, but the global protection limits remain in place

---

## VIII. NEXT DECISION SET — PERSISTENCE AND BOARD PROTOCOL DEFAULTS

These defaults define what the control board remembers and how it exchanges intent and status with the matrix board.

### DECISION 7: Persistence and Save Policy

**Question:** What game and service data should persist across power cycles?

**Options:**
- A) Minimal: only the most basic service settings persist
- B) Balanced: high scores, audits, and service settings persist locally
- C) Full logging: detailed per-game history and event logs persist

**Decision:**
```
Data scope: [ ] A) Minimal  [x] B) Balanced  [ ] C) Full logging
Storage owner: [x] Control board local nonvolatile storage
Write on every scoring event: [ ] Yes  [x] No
Write at end of ball: [x] Yes  [ ] No
Write on settings change: [x] Yes  [ ] No
Factory reset path: [x] Yes  [ ] No
```

**Reasoning (starting default):**
```
Keep the machine useful and serviceable without creating unnecessary flash wear or implementation complexity in the first pass.
```

**Default persisted items:**
- high score table
- service and bookkeeping counters
- audio and gameplay option flags
- protocol or configuration version marker for upgrades

---

### DECISION 8: Matrix-Board Command Protocol and Lamp Intent Model

**Question:** How should the control board and matrix board exchange gameplay information?

**Options:**
- A) Raw mirror: matrix board streams raw row and column state and the control board interprets everything
- B) Event and intent split: matrix board sends debounced switch and health events; control board sends lamp intent and mode commands
- C) Autonomous matrix: matrix board handles significant local game logic itself

**Decision:**
```
Interface model: [ ] A) Raw mirror  [x] B) Event and intent split via fixed register map  [ ] C) Autonomous matrix
Transport in v1: [x] I2C register map at 0x24
Explicit heartbeat register required in v1: [ ] Yes  [x] No
Health supervision in v1: [x] Poll switch and diagnostics registers with control-side timeout handling
Loss-of-link behavior: [x] Fail safe to non-destructive state
Protocol shape for MVP: [x] Lock to the shared v1 interface document
```

**Reasoning (starting default):**
```
The matrix board should handle the timing-sensitive work, while the control board remains the game-logic authority. For the MVP build, the cleanest alignment is the simpler register-map device already implemented in the matrix firmware rather than a richer future protocol.
```

**Default message classes:**
- matrix board to control board: debounced switch snapshot bytes at 0x40..0x43 plus diagnostics/status at 0xF0..0xF3
- control board to matrix board: global command bytes 0x20, 0x21, 0x80, 0x81, 0xE0..0xEF plus lamp row intent writes at 0x00..0x07

**Lamp contract default:**
- the control board expresses feature or lamp intent as an 8-byte row image
- the matrix board owns the actual multiplex timing and low-level lamp-drive behavior

---

## IX. ADDITIONAL LOCKED USER ANSWERS

### DECISION 9: Game and Maintenance Switch Definition

**Question:** How is service mode selected on the machine?

**Decision:**
```
SW2 function: [x] Game / Maintenance mode select
Switch type: [x] Maintained slide switch  [ ] Momentary
Mode interpretation: [x] Follow physical switch position
```

**Reasoning (locked answer):**
```
SW2 is a slide switch for Game versus Maintenance mode. It is not a momentary service button.
```

---

### DECISION 10: Audio Control and MVP Definition

**Question:** What must the first audio milestone include?

**Decision:**
```
Event MP3 playback for MVP: [x] Yes
Streaming required for MVP: [ ] Yes  [x] No
User-adjustable volume: [x] Yes
Persist volume setting: [x] Yes
```

**Reasoning (locked answer):**
```
Definition of done for the first audio pass is local event-driven MP3 playback with no streaming requirement yet, plus a user-facing way to adjust volume.
```

---

## X. ROUND 2 CLARIFICATION ANSWERS — LOCKED
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

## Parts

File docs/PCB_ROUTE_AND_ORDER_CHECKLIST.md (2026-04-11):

# PCB Route and Order Checklist

This is the **current follow-through checklist** now that the revised control-board PCB has been routed.

## Current checkpoint (2026-04-11)
- the revised control-board PCB has now been routed in KiCad
- the `TPS1H200A-Q1` devices (`U1`..`U5`) are now on the PCB
- the main `TPS1H200A-Q1` footprint-library mismatch has been corrected so those devices now point to the repo-local footprint library
- current file checks report **no errors found** for the schematic and PCB files

## Remaining library note
The main smart-switch footprint issue is fixed.

A few older project-specific footprints still use these external library names:
- `1My_Parts_ Passive:Slide Sw LCSC#C7498220` — 2 references
- `ESP32Vroom:CONN_SDA-41792_M450_23_MOL` — 1 reference

These are **not expected to block Gerber / drill export**, because the footprint geometry is already stored in the `.kicad_pcb` file.

If KiCad warns about them on another machine, the practical choices are:
1. keep using the current board as-is for fabrication output, or
2. later copy those legacy footprints into a repo-local library for full portability.

## Final pre-order checklist

### 1) KiCad review
- reopen the PCB and confirm the board still looks correct after the latest save
- run **DRC** in KiCad
- confirm there are no unexpected unrouted nets or accidental shorts

### 2) Mechanical / placement review
- verify connector orientation and pin numbering
- verify mounting holes and board outline
- verify silkscreen labels are readable and not covering pads
- verify polarity-sensitive parts still point the correct way

### 3) Power-path review
- re-check the `+22vdc` feed and `GND` return routing
- confirm the `TPS1H200A-Q1` channels have sensible copper around them for current and heat spreading
- confirm the output paths to `S2`..`S6` look direct and consistent

### 4) Fabrication settings
- confirm the intended board stackup is still what you want
- current KiCad board file shows a standard-looking `1.6 mm` board with `0.035 mm` copper layers
- verify any fab defaults (mask, copper weight, finish, color) before ordering

### 5) Manufacturing outputs
- generate **Gerbers**
- generate **drill files**
- if assembly is planned later, also export **BOM** and **pick-and-place / position** files
- zip the manufacturing outputs for the board house order

## Stop and fix before ordering if you see
- any DRC errors that are real electrical or spacing problems
- any connector orientation doubt
- any too-thin high-current path on the `+22vdc` or output routing
- any missing or obviously wrong footprint on the revised smart-switch channels

## What happens after the order
- order the revised board
- when the boards arrive, return to `docs/NEXT_STEP_BENCH_PLAN.md` and `docs/FIRST_POWERUP_CHECKLIST.md`
- start with safe checks and controlled bring-up, one channel at a time

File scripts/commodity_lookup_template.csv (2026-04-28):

Commodity_Spec | DigiKey_PN | Description | Notes
RES 10kohm 1% 0805 >=125mW |  | 10k 0805 resistor | Fill with your preferred Digi-Key stock code
CAP 0.1uF X7R 50V 0805 |  | 100nF 0805 capacitor | Fill with your preferred Digi-Key stock code

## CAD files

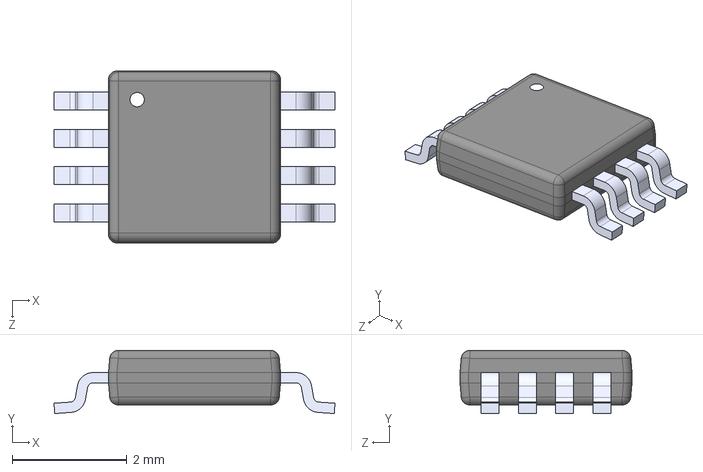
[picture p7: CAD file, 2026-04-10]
hardware/control-board/kicad-lib/3dmodels/TPS1H200AQDGNRQ1.step
4.90 x 1.10 x 3.00 mm

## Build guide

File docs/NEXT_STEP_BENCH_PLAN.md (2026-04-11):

# Next Step Bench Plan

This is the **simple, one-thing-at-a-time** plan for the current control-board work.

> For now, **do not apply the real `+22vdc` / `26 V` solenoid supply yet**. First prove the logic side and the board basics on current-limited `5 V` only.

## Where we are now
- the solenoid-driver direction is now **`TPS1H200A-Q1`**
- the repeated channels for `S2`..`S6` have been duplicated into the schematic
- the project-local KiCad symbol / footprint / 3D model files are now in the repo
- the latest schematic checkpoint has already been saved to GitHub

## Immediate next step

### 1) Meter checks with the board unpowered
- check `5V` to `GND` for a short
- check `+22vdc` to `GND` for a dead short
- check there is **not** accidental continuity between the `+22vdc` rail and the `5V` logic rail
- if anything looks wrong here, stop before applying power

### 2) First power-up on `5V` only
- set the bench supply to `5V`
- use a conservative current limit
- leave the real coil / solenoid supply disconnected
- watch for unexpected current draw, hot parts, smoke, or smell
- confirm the expected logic rail behavior and MCU boot behavior

### 3) If the `5V` test behaves normally
- validate **one `TPS1H200A-Q1` channel at a time**
- keep the current `CL` resistor value as a **placeholder** until the bench proves it
- keep `DELAY` in the simple non-auto-retry direction for now
- record what happens in `docs/TPS1H200_CL_DELAY_BENCH_TABLE.md`

## What is coming after this
- finalize the `CL` resistor value and any `DIAG_EN` default choice
- clean up any last schematic details after bench learning
- carry the repeated smart-switch pattern into the PCB / layout work
- move into controlled coil testing and then wider board bring-up
- keep the firmware / HAT-board workflow moving in parallel

## Simple roadmap
- **Now:** safe meter checks and `5V`-only bring-up
- **Next:** one-channel smart-switch validation
- **Then:** freeze support values and clean up schematic / PCB details
- **After that:** next board-spin decisions and broader system integration

## Focus note
You do **not** need to hold the whole project in your head at once.

The only thing to focus on right now is: **safe bench checks first, one step at a time**.

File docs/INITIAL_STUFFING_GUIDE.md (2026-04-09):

# Initial Stuffing Guide for 5 V Firmware Bring-Up

Use this guide to decide what to populate now versus what can wait while the board is being brought up for **firmware development only**.

> This is a development-first recommendation, not the final production stuffing plan.

## Goal
Get the board to a safe state where the MCU and logic can be powered and tested on **5 V only**, while avoiding the risky **26 V solenoid-drive** condition until the `Vgs` issue is addressed.

## Populate now
These are the parts worth populating for the first bring-up pass:

- the **MCU / controller section** needed to boot firmware
- any **logic-side power path** needed for 5 V bring-up
  - 5 V input connection used for the bench supply
  - any regulator or local logic rail parts needed to generate the MCU supply
  - decoupling capacitors and basic power filtering
- **reset / boot / programming / debug** parts
- **USB / serial / header** parts needed to load firmware or observe boot logs
- **status LEDs** and their resistors, if they help bring-up
- input-side connectors or headers needed for safe logic testing
- the board-to-board connector parts needed to use the current **HAT-board workaround** during development
- test points or probe-friendly headers that help verify rails and GPIO activity

## Safe to leave off initially
If these parts are not needed for first firmware work, they can be left unpopulated for now:

- real **solenoid load connectors and field wiring**
- high-current output terminals that are not needed during logic bring-up
- optional indicator or convenience parts that do not affect boot, power, or debug access

## Recommended to leave off until the 26 V issue is controlled
For the safest first pass, avoid populating parts that only matter to the live high-voltage solenoid path unless you specifically need them mounted for fit-checking.

This especially includes the **solenoid-drive MOSFET chain** identified in the current schematic, such as:
- `IRFR5410` output devices in the solenoid path
- `BSS84` P-channel gate-drive devices associated with that path
- any other parts that exist only to switch or support the live **26 V** solenoid rail

## If the board is already fully stuffed
If those parts are already installed, the board can still be used for early firmware work **provided the real 26 V supply remains disconnected** and the solenoid outputs are treated as inactive during bring-up.

Recommended precautions:
- power the logic section from a **current-limited 5 V bench supply**
- if you want output-stage proof-of-life only, feed the output rail from that same **5 V** source rather than from 22–26 V
- do not connect real solenoid loads yet
- do not test live high-energy output switching yet
- monitor current draw and part temperature during the first boot

## Practical first-pass recommendation
### Best path for fastest safe bring-up
1. populate the **logic, MCU, power, and debug** sections first
2. leave the **26 V solenoid-drive section** out if practical
3. bring the board up on **5 V only**
4. verify boot, serial output, GPIO behavior, and any safe low-energy interfaces
5. return to the solenoid section only after the temporary workaround or redesign is defined

## Related docs
- `docs/BENCH_STUFFING_CHECKLIST.md`
- `docs/FIRST_POWERUP_CHECKLIST.md`
- `docs/REV_B_ACTION_LIST.md`
- `docs/NEXT_ITERATION.md`

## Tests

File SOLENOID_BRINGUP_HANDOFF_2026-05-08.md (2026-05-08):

# Solenoid Bring-Up Handoff — 2026-05-08

## Session Summary

**Primary Goal**: Validate Rev 1 control board TPS1H200A solenoid drivers for 22V coil rail.

**Status**: 4 of 5 solenoids working with TPS output stage. **Outhole (S2) requires relay workaround** due to current-limit constraint on TPS CL/ILIM pin.

---

## What Was Done This Session

### Hardware Changes
1. **Solenoid CL/ILIM resistors**: Stepped down from `1kΩ` → `510Ω` → `270Ω` → `150Ω` → `0Ω`
   - Progression: `~1.5A` → `~3A` → `~5.5A` → `~9A` → `device max`
   - Result: S2 (outhole) did not achieve sufficient force even with 0Ω (no current limit)

2. **GPIO5 strapping pin issue discovered**: GPIO5 is an ESP32 boot-time strapping pin pulled HIGH during reset, which would latch S5 (bumper) coil ON at boot. **Firmware fix applied**: reversed `pinMode`/`digitalWrite` order in `initSolenoids()` to avoid glitch during init. **Board hardware fix needed**: add 10kΩ pull-down from U5 (S5 channel) IN pin to GND.

3. **510Ω CL setting is current standard** on all five TPS1H200A channels. All solenoids connected to 22V main supply.

### Firmware Changes (Control-and-Hat-Board repo)

#### `firmware/control-board/include/solenoid_gpio_config.h`
- S2 (outhole) pulse width: `45ms` → `100ms` (extended for mapping/force validation)
- Other solenoids: unchanged (`45ms`, `45ms`, `40ms`, `40ms`)

#### `firmware/control-board/src/main.cpp`
1. **Single-channel test mode**: Output test loop now fires **only S2** repeatedly (not cycling through all 5)
   - Added: `constexpr uint8_t OUTPUT_TEST_SINGLE_SOLENOID = SOLENOID_S2`
   - Modified `runOptionalOutputTest()` to: `activeOutput = static_cast<int8_t>(OUTPUT_TEST_SINGLE_SOLENOID);`
   - Simplified serial debug output

2. **GPIO init order fix**: `initSolenoids()` now writes `digitalWrite(LOW)` **before** `pinMode(OUTPUT)` to avoid drive glitch during power-on

3. **Firmware flashed to COM5**: `captain_control_test` environment, build successful, uploaded successfully.

---

## Current Test State

**Firmware**: `captain_control_test` profile (TEST mode)
- Fires only S2 (outhole) repeatedly
- Pulse: `100ms` ON, `~750ms` idle between pulses
- Cycles endlessly, prints per pulse on serial

**Hardware**:
- All 5 solenoids connected to 22V main supply
- All 5 TPS1H200A channels set to `510Ω` CL/ILIM
- GPIO5 init fix applied (firmware-side; still need 10k pull-down on board for full fix)

**Test Results**:
- **S3, S4, S5, S6**: Working, audible clicks, reasonable force
- **S2 (outhole)**: Operating but insufficient force to eject ball reliably even at 100ms and with CL shorted (0Ω)
- **GPIO5 spurious firing**: Fixed at boot time with init order change

---

## Root Cause Analysis: S2 Outhole

TPS1H200A device specs:
- Max continuous current: **10A** (nominal)
- Max peak current: limited by coil impedance + supply

Observations:
- Even with `CL` shorted to GND (unlimited current), outhole did not achieve target force
- This suggests: **The outhole coil itself, the plunger mechanics, or the wiring path has an impedance/friction issue**, not a board current-limit issue

**Not the board. Likely coil/mechanical.**

---

## Next Steps: Outhole Workaround (Relay Bridge)

### The Plan
Replace TPS S2 output stage with a **24V automotive relay** driven from the same ESP32 GPIO.

**Wiring**:
```
GPIO23 ──────────► Relay coil + (via current-limiting resistor or direct)
GND  ─────────────► Relay coil -
+24V supply ──────► Relay contact COM
Relay contact NO ─► Outhole solenoid +
Outhole solenoid - ► GND
```

**Parts Needed**:
1. 24V DC automotive relay (SPST-NO or SPDT), 20A+ contact rating, **with mounting tab and socket harness** (surface-mount)
2. Flyback diode across relay coil (`1N4007`, cathode to coil +, anode to coil -)
3. Flyback diode across solenoid coil (likely already present on machine)
4. Fuse holder + fuse for +24V branch

**Why This Works**:
- Relay coil only draws ~50–80mA (well within TPS capability)
- Relay contacts deliver full 24V at unlimited current to the solenoid
- Relay delay (~5–10ms) is **irrelevant for outhole** — ball sits idle anyway
- No board revision required
- No firmware change required

### Parallel Work: Debug the Outhole Coil Path

While waiting for relay parts, optionally bench-test:
1. Disconnect outhole coil from board
2. Feed it direct 24V from supply for ~100ms pulse manually
3. Observe if it achieves target force
4. If yes: wiring/board path is the issue
5. If no: coil or mechanics is the issue

---

## Firmware Status: Future Changes

### To Revert After Relay Workaround Installed
Once relay is wired and tested:
1. Keep S2 pulse at **60–80ms** (relay has no current limit, so force is achievable)
2. Revert to **all-five-channel cycling** test mode for full system validation
3. Flash `captain_control_test` and verify all 5 solenoids fire in sequence

### Eventual Production Firmware
Switch to `captain_control_system` profile (non-test mode) once hardware bringup is complete. Will require:
- I2C slave implementation on matrix board (0x24 address)
- `onMatrixSwitchEdge()` callback to couple solenoid firing to switch closure
- Scoring state machine
- Audio integration

---

## Files Modified This Session

| File | Change |
|---|---|
| `firmware/control-board/include/solenoid_gpio_config.h` | S2 pulse: `45ms` → `100ms` |
| `firmware/control-board/src/main.cpp` | Single-channel S2 test mode + GPIO init order fix |

---

## Known Issues / Board Revision Candidates

1. **GPIO5 strapping pull-up at boot**: Add 10kΩ pull-down from U5 (S2 channel) IN pin to GND to suppress spurious S5 firing on reset
2. **S2 TPS output insufficient**: Either coil/mechanics weak, or board path has impedance. Relay workaround in place; debug coil path if time permits.

---

## Git Commits

- **Commit hash**: [will be updated after push]
- **Message**: `Solenoid bring-up: S2 to 100ms, single-channel test mode, GPIO5 init fix`
- **Files**: 
  - `firmware/control-board/include/solenoid_gpio_config.h`
  - `firmware/control-board/src/main.cpp`

---

## Resume Checklist

When you return:

- [ ] Relay parts ordered/on-hand
- [ ] Relay wired to GPIO23, TPS S2 output disabled/rerouted
- [ ] Flyback diodes installed on relay coil and solenoid coil
- [ ] Test: S2 fires reliably with relay (should achieve full force now)
- [ ] Revert firmware to all-five-channel cycling
- [ ] Reflash `captain_control_test` to COM5
- [ ] Verify all 5 solenoids cycle (S2 with relay, others with TPS)
- [ ] Document relay test results in new handoff
- [ ] Consider: Debug outhole coil direct-power test (optional bench work)
- [ ] Move to Priority 1: I2C slave implementation on matrix board

---

## Contact Points

- **ESP32 Control Board**: COM5 (baud 115200)
- **Matrix Board**: COM4 (baud 115200)
- **Current Firmware**: `captain_control_test` (single-channel S2 mode, 100ms pulse)
- **Current Pulse Timing**: S2 fires, ~750ms idle, repeats

---

**Session End**: 2026-05-08 (session paused for location change)  
**Next Session**: TBD (after relay procurement and installation)

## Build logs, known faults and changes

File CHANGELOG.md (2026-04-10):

# Changelog

All notable changes to this repo will be documented here.

## [Unreleased]
### Added
- initial focused repo scaffold for the Captain Fantastic control board and HAT board redesign
- baseline control-board and HAT-board KiCad sources copied from the main Captain Fantastic repo
- project status and next-iteration parking-lot notes
- `docs/REV_B_ACTION_LIST.md` with the first concrete redesign checklist for the 26 V solenoid issue and HAT-board connector alignment issue
- `docs/FIRST_POWERUP_CHECKLIST.md` for the staged 5 V-only firmware bring-up process
- `docs/INITIAL_STUFFING_GUIDE.md` with a practical populate-now vs populate-later recommendation for safe first bring-up
- `docs/BENCH_STUFFING_CHECKLIST.md` as a short assembly-side checklist for the first 5 V bring-up build
- `docs/FIRMWARE_MIGRATION.md` plus a clean `firmware/control-board/` baseline to start merging the old control firmware into this repo
- `docs/OLED_DEBUG_DISPLAY.md` and SSD1306-oriented boot-time I2C/OLED support in the new firmware baseline for the added .96-inch troubleshooting display
- `docs/SOLENOID_DRIVER_SELECTION.md` documenting the current driver-direction decision: move away from the discrete PMOS stage and toward a smart high-side switch for the respin
- `docs/SINGLE_CHANNEL_SOLENOID_LAYOUT.md` locking in the easier single-channel layout approach for the five control-board solenoid outputs
- `docs/SMART_SWITCH_CHANNEL_BLOCK.md` defining the repeated per-channel smart-switch schematic block for `S2..S6`
- locked the single-channel smart-switch choice to `TPS1H200A-Q1` as the control-board baseline direction
- added a visible Rev B smart-switch/layout note directly into `hardware/control-board/Pinball Control board.kicad_sch`

### Changed
- merged the current uploaded KiCad files for both boards into the organized `hardware/` layout
- archived older control-board snapshot files under `hardware/control-board/archive/`
- clarified in the docs that the HAT board is a companion board created by splitting the original control board during development, not a revision of it
- documented the first two must-fix redesign issues: the 26 V solenoid-driver problem and the HAT-board connector misalignment
- updated the plan to reflect a development-first approach, including the connector workaround and the `Vgs` concern on the solenoid-drive path
- added the staged **5 V only** bring-up plan for initial firmware development with the 26 V solenoid rail left disconnected

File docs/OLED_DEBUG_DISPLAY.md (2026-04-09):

# OLED Debug Display Notes

A **.96-inch SSD1306-style I2C OLED** has been added to the control-board design to help with:
- boot messages
- troubleshooting status
- quick local diagnostics without depending only on serial output

## Current intent
For now, the OLED is treated as a **bring-up aid** for the new firmware baseline under `firmware/control-board/`.

## What is already in place
- the clean control-board `main.cpp` now scans the I2C bus during bring-up
- the firmware now targets the common **SSD1306** controller family directly
- expected debug OLED addresses are currently tracked as `0x3C` and `0x3D`
- serial boot output reports whether a likely OLED device is detected on the shared I2C bus
- when the OLED initializes successfully, it shows a simple local bring-up status message

## Current assumption
This is being treated as the common **128x64 `.96-inch` SSD1306-style module** unless later bench testing proves otherwise.

## Next step for richer on-screen text
Once the display is confirmed on the bench, the next step is to expand from simple bring-up text into more detailed boot logs, status pages, or troubleshooting readouts.

## Bring-up note
Keep the OLED on the normal low-voltage I2C side of the board during the current **5 V bench bring-up**. It fits well with the current troubleshooting-first development flow.

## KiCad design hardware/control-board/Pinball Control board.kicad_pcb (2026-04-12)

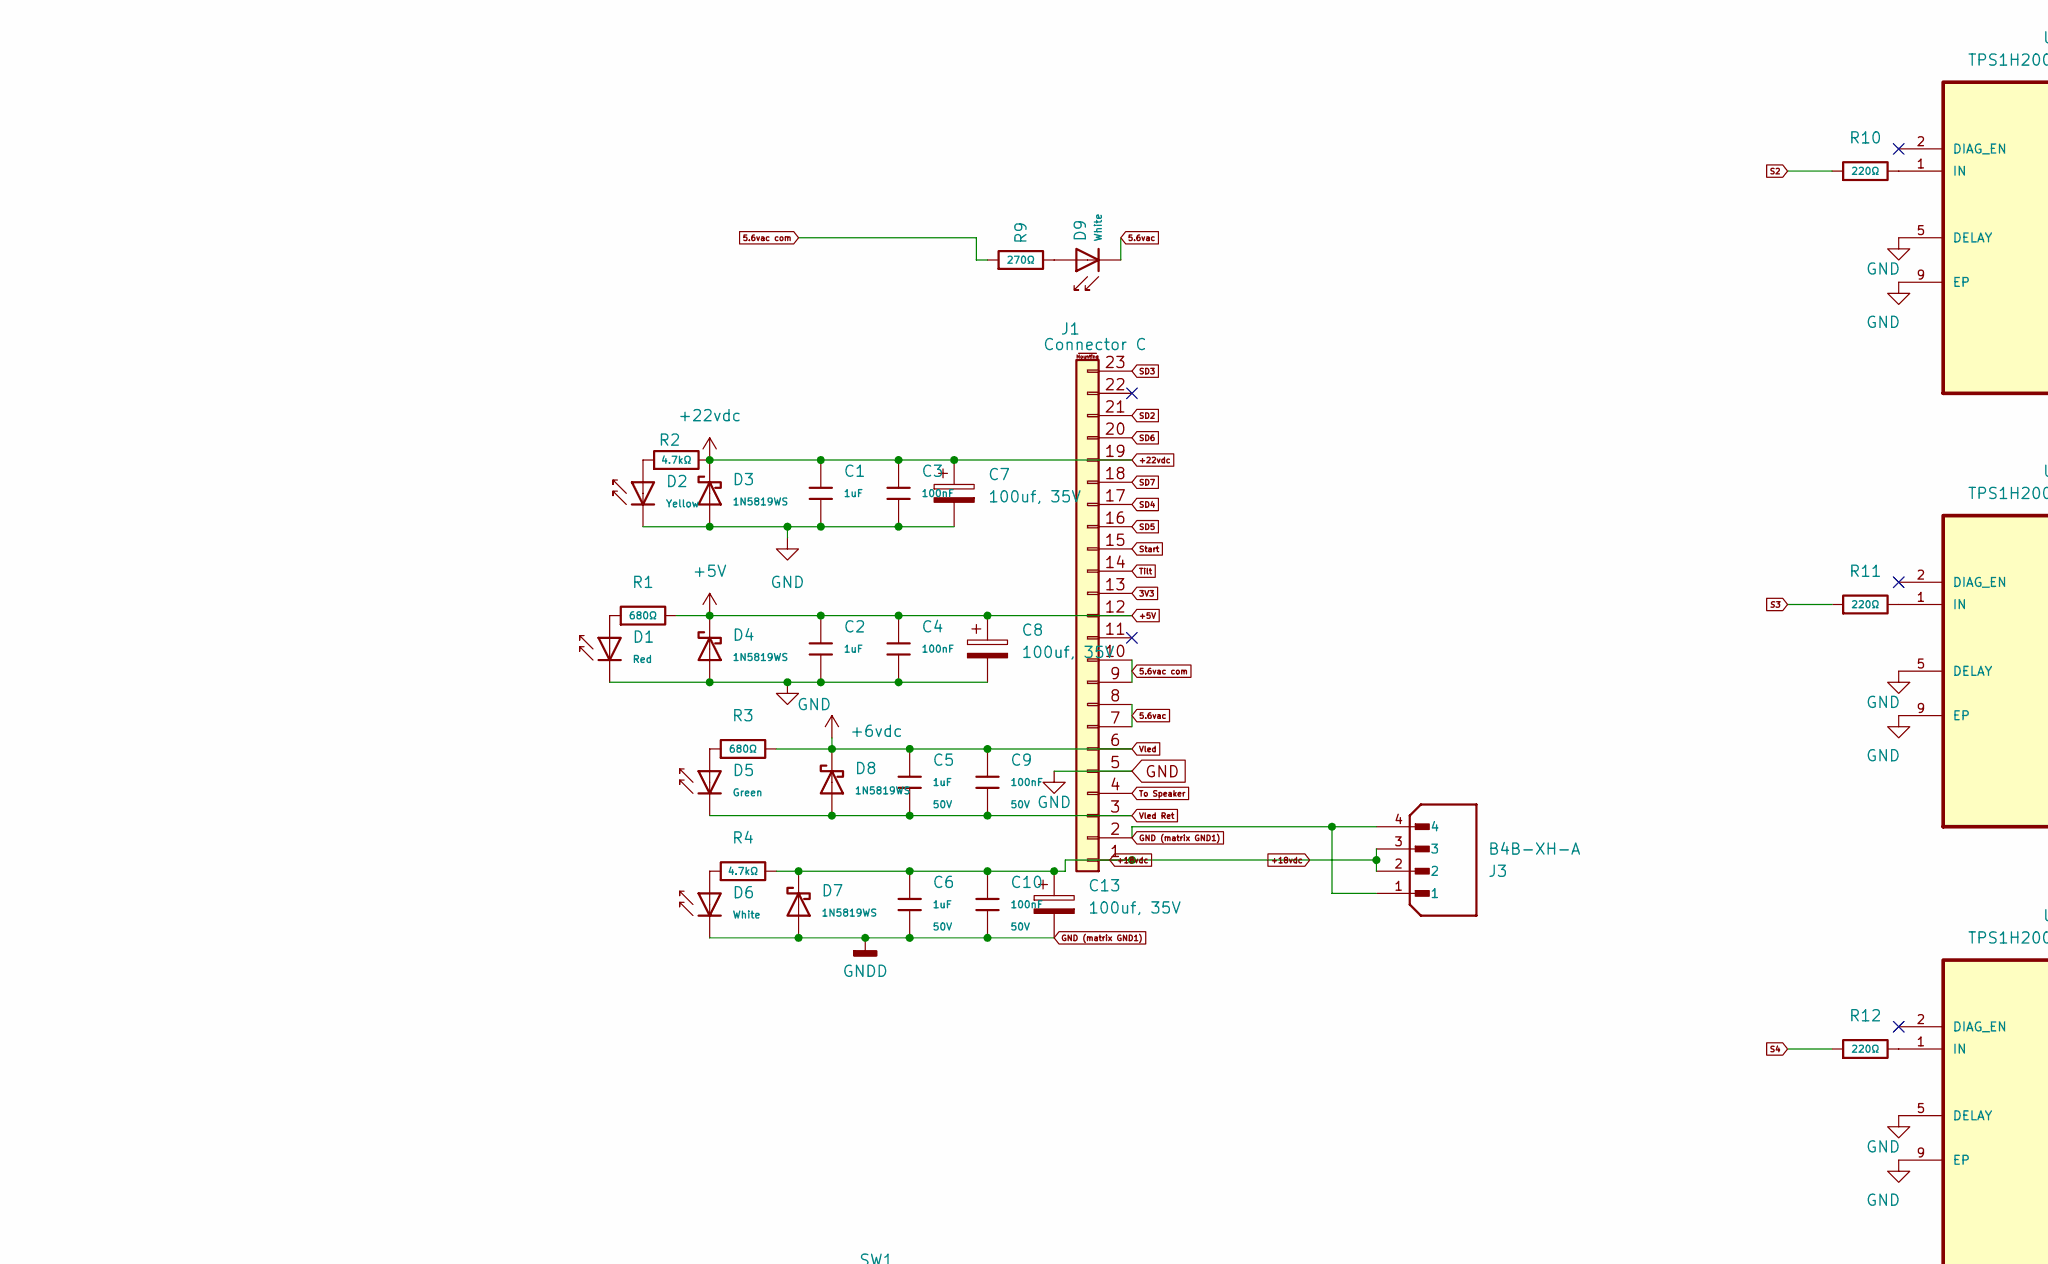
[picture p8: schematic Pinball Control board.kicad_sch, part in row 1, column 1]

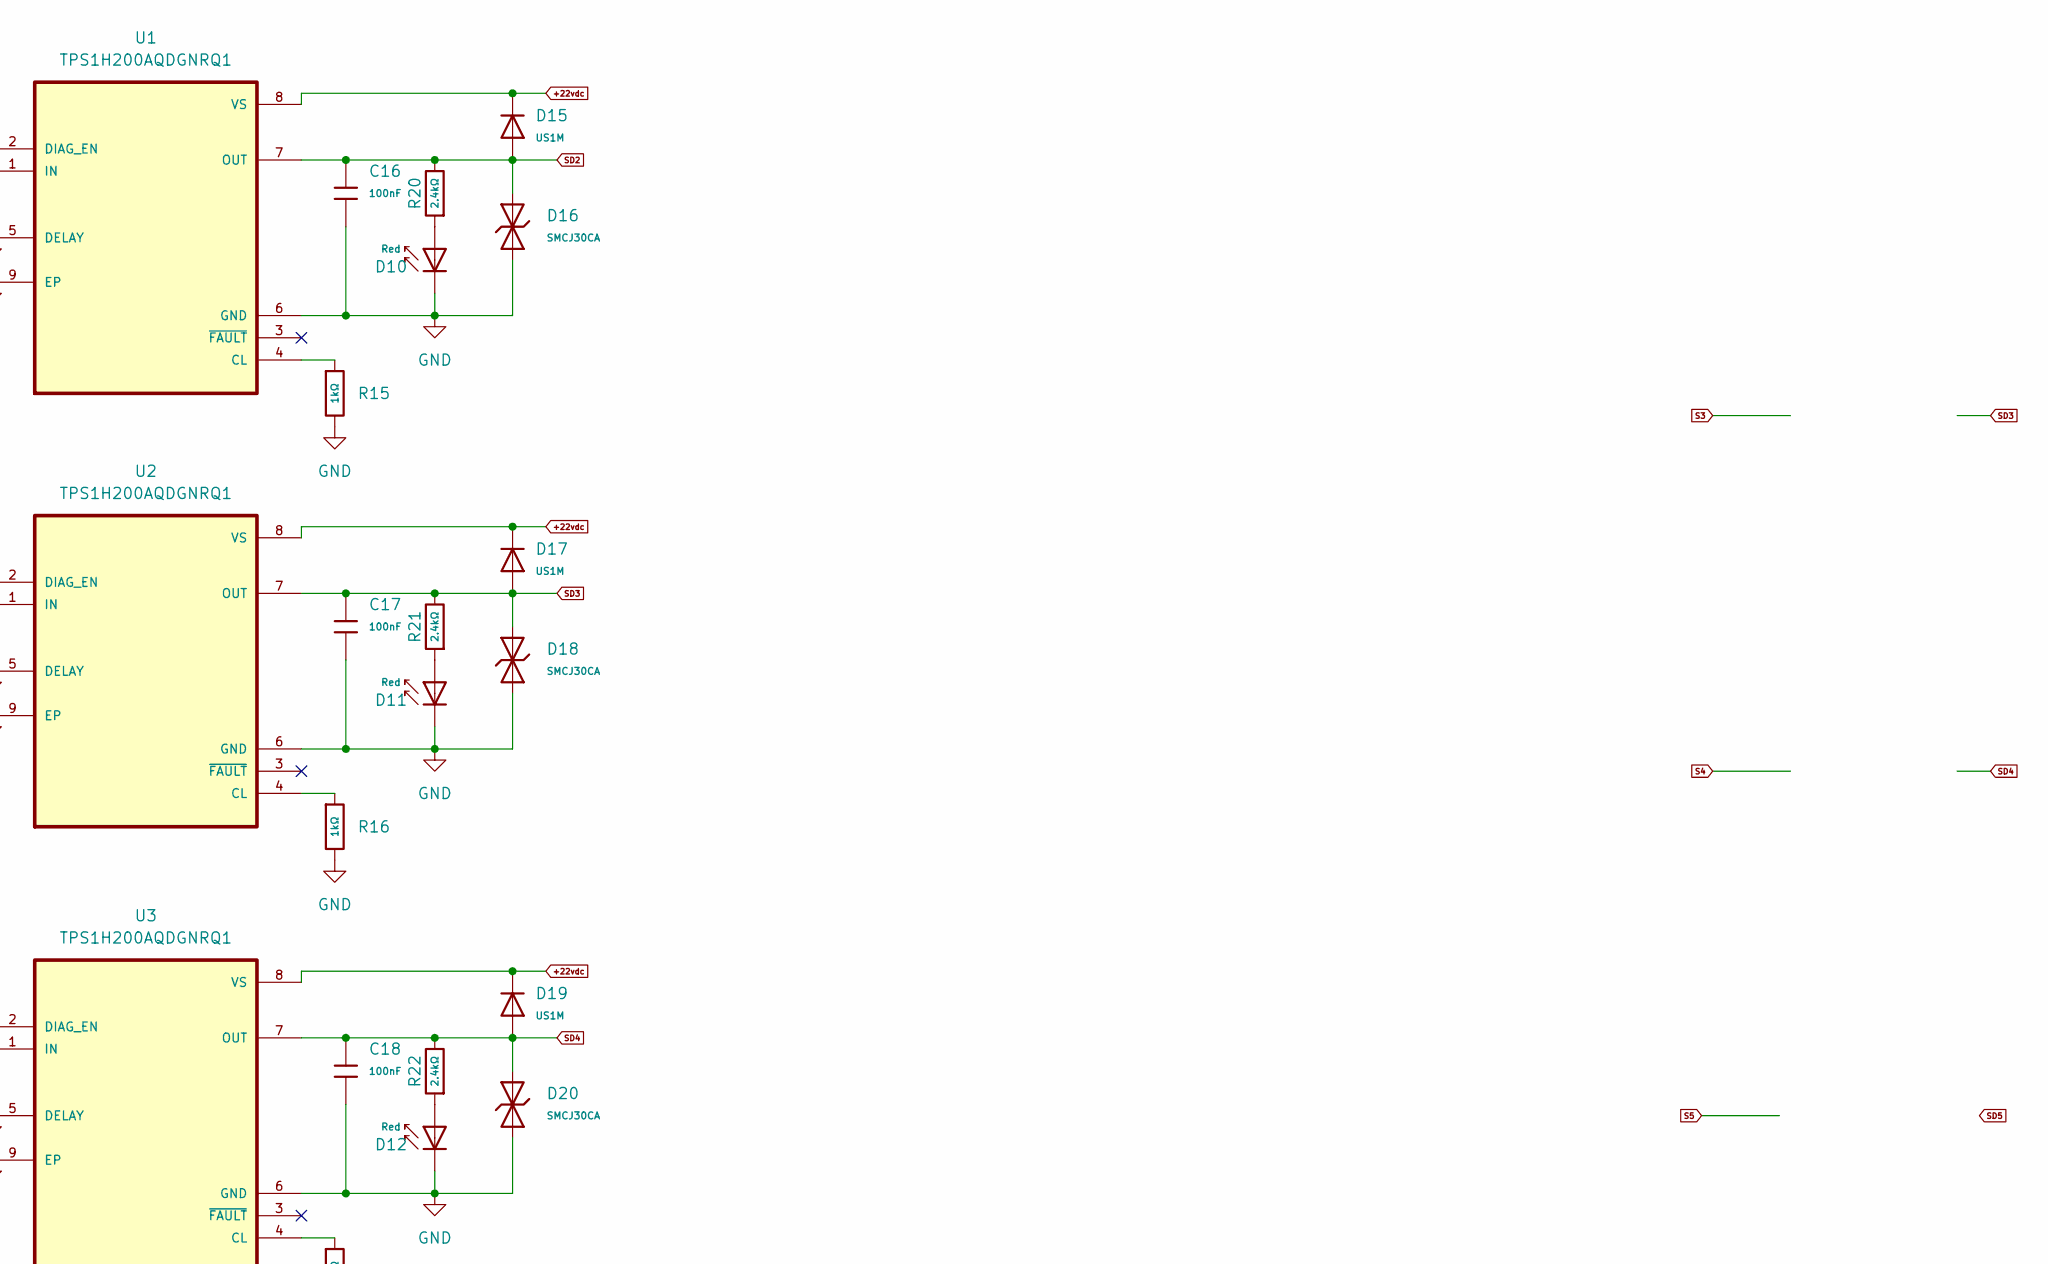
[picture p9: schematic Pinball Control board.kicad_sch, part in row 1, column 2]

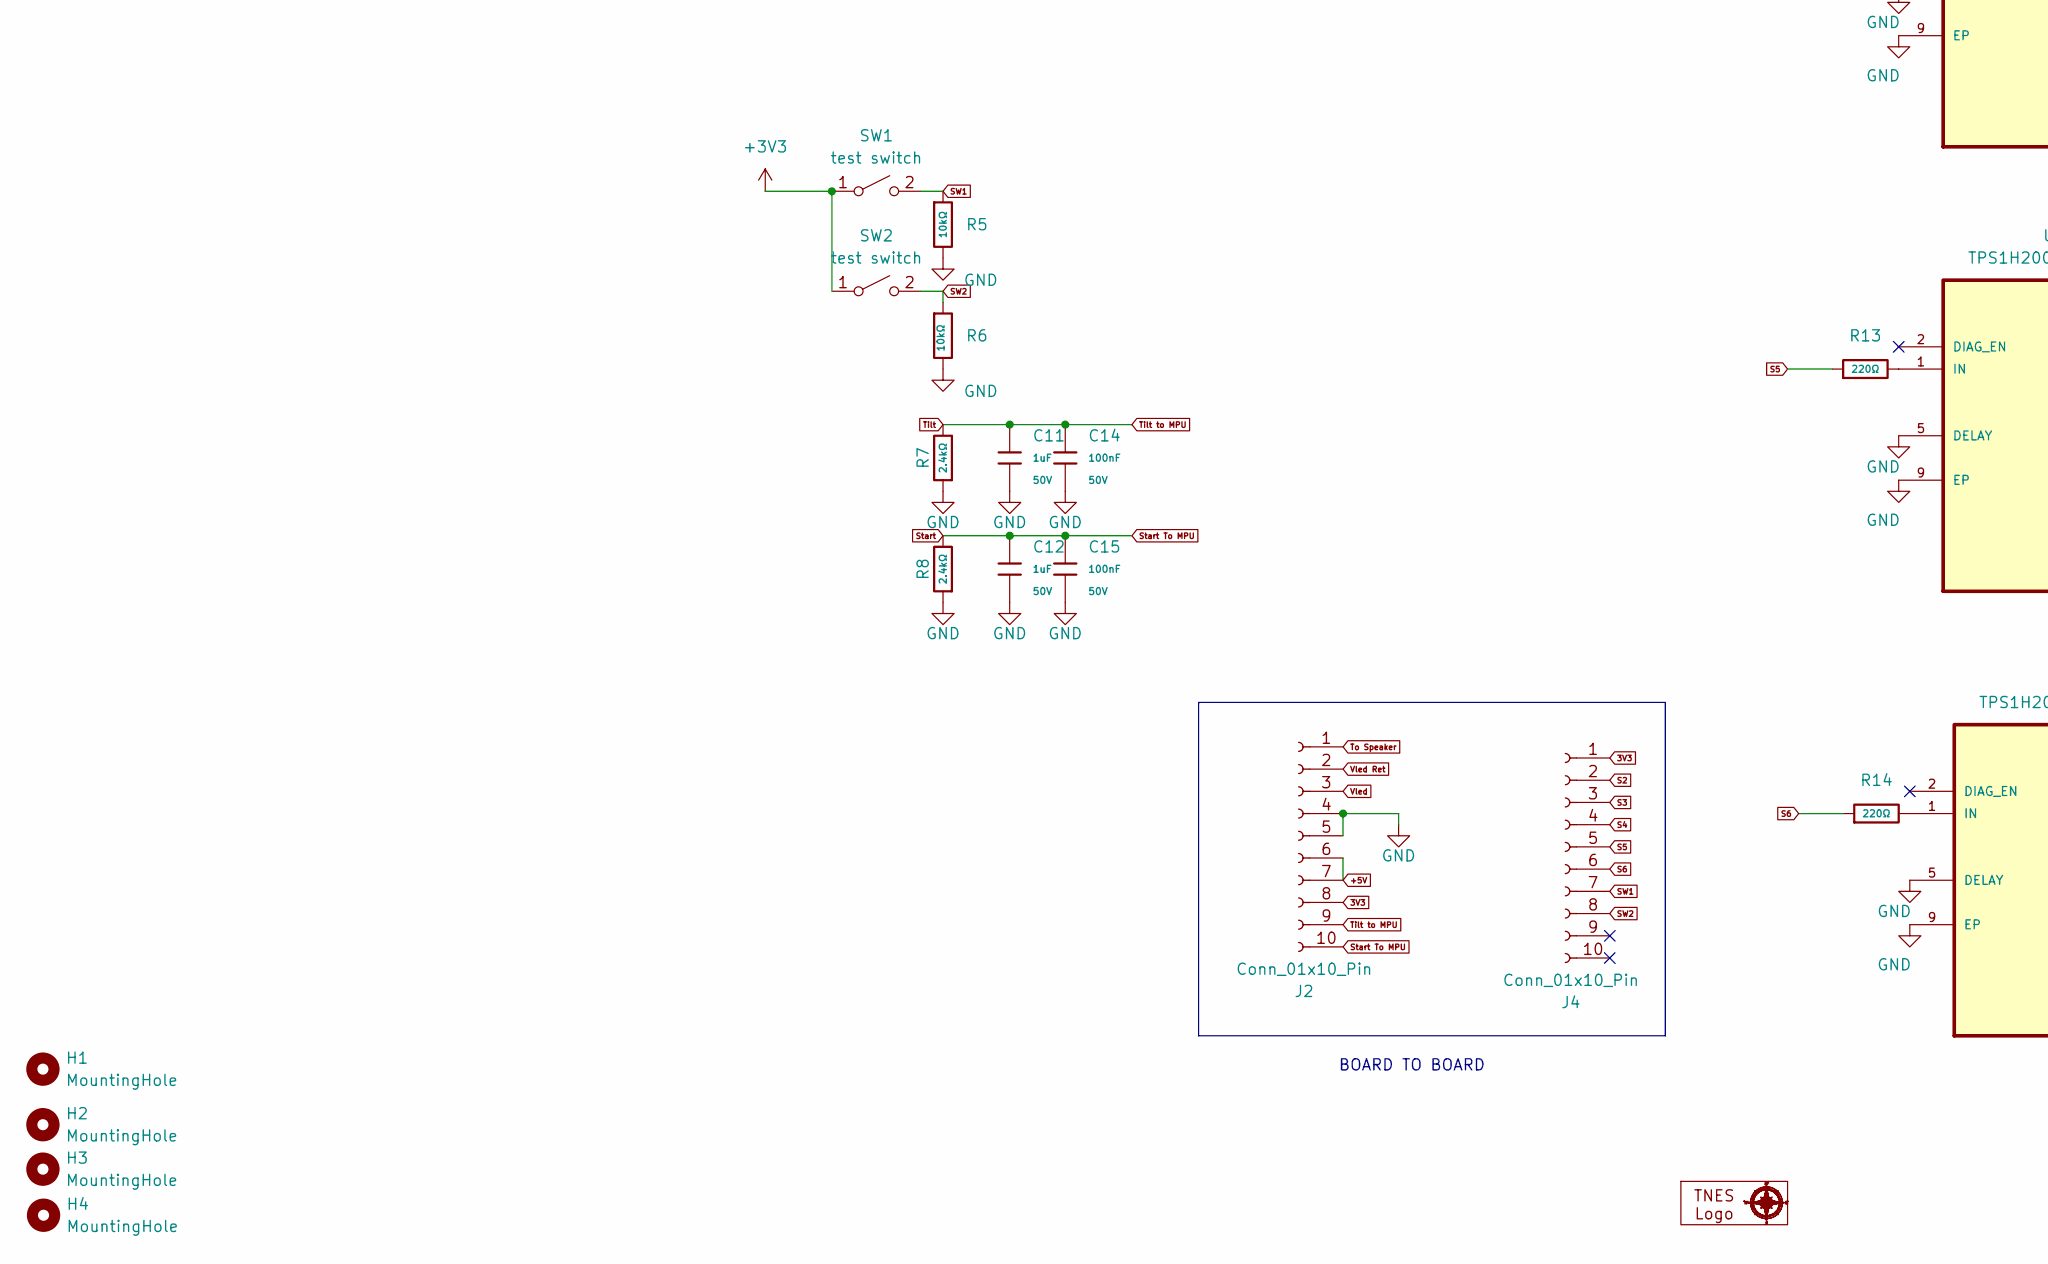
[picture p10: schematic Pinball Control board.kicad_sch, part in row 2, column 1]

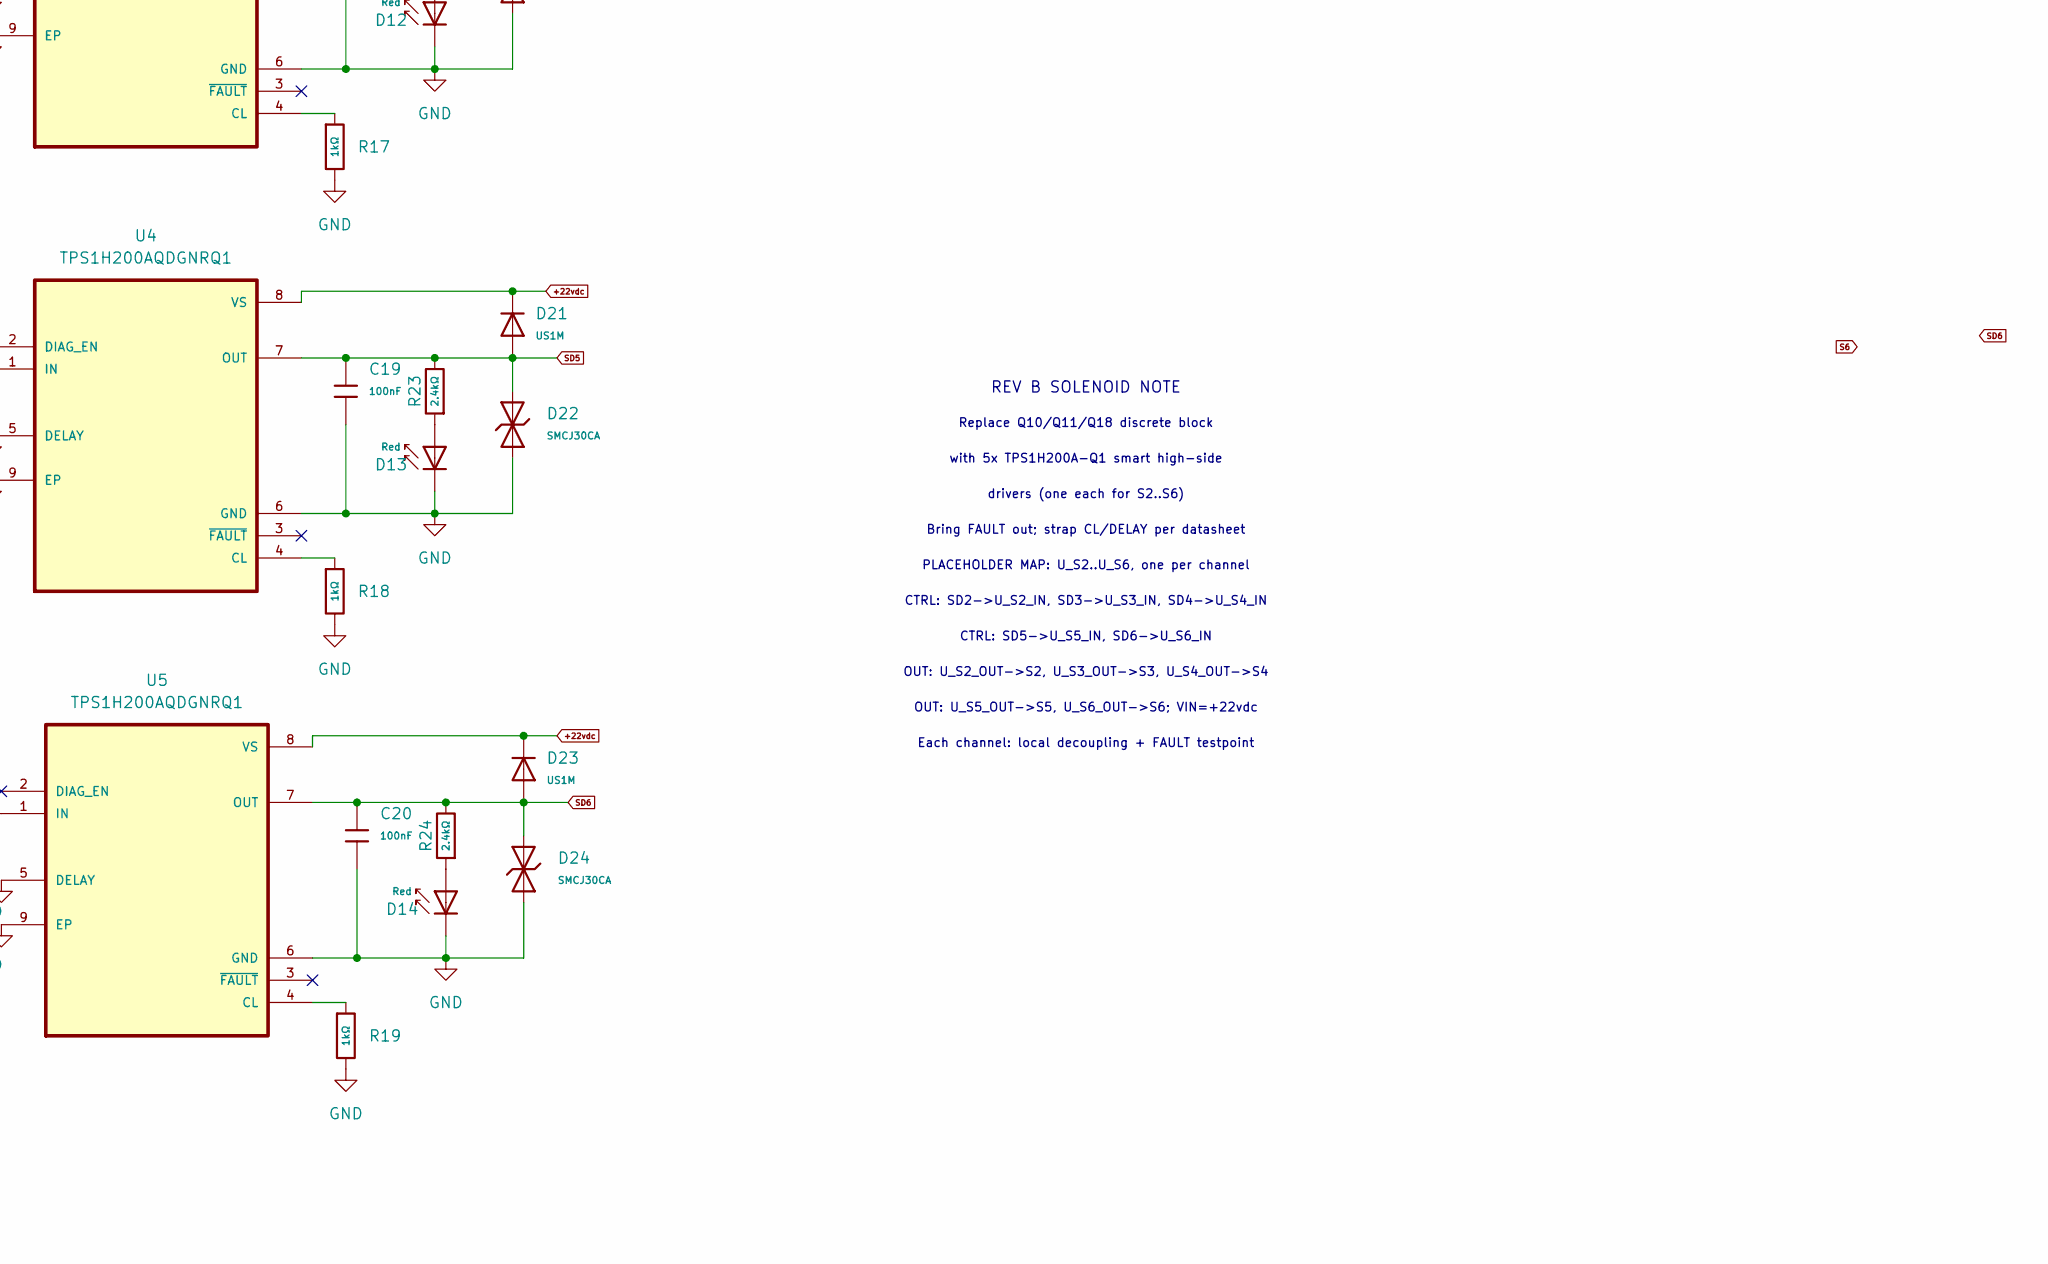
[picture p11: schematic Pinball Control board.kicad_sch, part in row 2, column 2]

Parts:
10mm1: 10mm LOGO
C1, C2, C5, C6, C11, C12: 1uF; C_0805; Voltage Rated 50V; Tolerance ±10%; Part CL21B105KBFNNNE; LCSC C28323
C3, C4, C9, C10, C14, C15, C16, C17, C18, C19, C20: 100nF; C_0805; Voltage Rated 50V; Tolerance ±10%; Part CC0805KRX7R9BB104; LCSC C49678
C7, C8, C13: 100uf, 35V; CP_Radial_D6.3mm_P2.50mm; LCSC C122240
D1, D10, D11, D12, D13, D14: Red; D_0805; Forward Voltage (VF) 1.6V~2.6V; Part NCD0805R1; LCSC C84256
D2: Yellow; D_0805; Part KT-0805Y; LCSC C2296
D3, D4, D7, D8: 1N5819WS; D_SOD-323; Forward Voltage (Vf@If) 600mV@1A; Reverse Voltage (Vr) 40V; Part 1N5819WS; LCSC C191023
D5: Green; D_0805; Part KT-0805G; LCSC C2297
D6, D9: White; D_0805; Part KT-0805W; LCSC C34499
D15, D17, D19, D21, D23: US1M; D_SMA; Forward Voltage (Vf@If) 1.65V@1A; Reverse Voltage (Vr) 1kV; Part US1M; LCSC C412437
D16, D18, D20, D22, D24: SMCJ30CA; D_SMC; Part SMCJ30CA; LCSC C19077607
H1, H2, H3, H4: MountingHole; MountingHole_3.5mm_Pad
J1: Connector C; CONN_SDA-41792_M450_23_MOL
J2, J4: Conn_01x10_Pin; PinHeader_1x10_P2.54mm_Vertical
J3: B4B-XH-A; JST_EH_B4B-EH-A_1x04_P2.50mm_Vertical; PARTREV 7/4/21
R1, R3: 680Ω; R_0805; Overload Voltage (Max) 150V; Tolerance ±1%; Part 0805W8F6800T5E; LCSC C17798
R2, R4: 4.7kΩ; R_0805; Overload Voltage (Max) 150V; Tolerance ±1%; Part 0805W8F4701T5E; LCSC C17673
R5, R6: 10kΩ; R_0805; Overload Voltage (Max) 150V; Tolerance ±1%; Part 0805W8F1002T5E; LCSC C17414
R7, R8, R20, R21, R22, R23, R24: 2.4kΩ; R_0805; Overload Voltage (Max) 150V; Tolerance ±1%; Part 0805W8F2401T5E; LCSC C17526
R9: 270Ω; R_0805; Overload Voltage (Max) 150V; Tolerance ±1%; Part 0805W8F2700T5E; LCSC C17590
R10, R11, R12, R13, R14: 220Ω; R_0805; Overload Voltage (Max) 150V; Tolerance ±1%; Part 0805W8F2200T5E; LCSC C17557
R15, R16, R17, R18, R19: 1kΩ; R_0805; Overload Voltage (Max) 150V; Tolerance ±1%; Part 0805W8F1001T5E; LCSC C17513
SW1, SW2: test switch; Slide Sw LCSC#C7498220; LCSC C7498220
U1, U2, U3, U4, U5: TPS1H200AQDGNRQ1; SOP65P490X110-9N

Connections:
3V3: J1.13, J2.8, J4.1
5.6vac: D9.1, J1.7, J1.8
5.6vac com: J1.9, J1.10, R9.1
+3V3: SW1.1 (A), SW2.1 (A)
+5V: C2.1, C4.1, C8.1, D4.1, J1.12, J2.6, J2.7, R1.2
+18vdc: C6.1, C10.1, C13.1, D7.1, J1.1, J3.2, J3.3, R4.2
+22vdc: C1.1, C3.1, C7.1, D3.1, D15.1, D17.1, D19.1, D21.1, D23.1, J1.19, R2.2, U1.8 (VS), U2.8 (VS), U3.8 (VS), U4.8 (VS), U5.8 (VS)
GND: C1.2, C2.2, C3.2, C4.2, C7.2, C8.2, C11.2, C12.2, C14.2, C15.2, C16.2, C17.2, C18.2, C19.2, C20.2, D1.1, D2.1, D3.2, D4.2, D10.1, D11.1, D12.1, D13.1, D14.1, D16.1, D18.1, D20.1, D22.1, D24.1, J1.5, J2.4, J2.5, R5.2, R6.2, R7.1, R8.1, R15.2, R16.2, R17.2, R18.2, R19.2, U1.5 (DELAY), U1.6 (GND), U1.9 (EP), U2.5 (DELAY), U2.6 (GND), U2.9 (EP), U3.5 (DELAY), U3.6 (GND), U3.9 (EP), U4.5 (DELAY), U4.6 (GND), U4.9 (EP), U5.5 (DELAY), U5.6 (GND), U5.9 (EP)
GND (matrix GND1): C6.2, C10.2, C13.2, D6.1, D7.2, J1.2, J3.1, J3.4
unnamed: D1.2, R1.1
unnamed: D2.2, R2.1
unnamed: D5.2, R3.1
unnamed: D6.2, R4.1
unnamed: D9.2, R9.2
unnamed: D10.2, R20.1
unnamed: D11.2, R21.1
unnamed: D12.2, R22.1
unnamed: D13.2, R23.1
unnamed: D14.2, R24.1
unnamed: R15.1, U1.4 (CL)
unnamed: R10.2, U1.1 (IN)
unnamed: R16.1, U2.4 (CL)
unnamed: R11.2, U2.1 (IN)
unnamed: R17.1, U3.4 (CL)
unnamed: R12.2, U3.1 (IN)
unnamed: R18.1, U4.4 (CL)
unnamed: R13.2, U4.1 (IN)
unnamed: R19.1, U5.4 (CL)
unnamed: R14.2, U5.1 (IN)
S2: J4.2, R10.1
S3: J4.3, R11.1
S4: J4.4, R12.1
S5: J4.5, R13.1
S6: J4.6, R14.1
SD2: C16.1, D15.2, D16.2, J1.21, R20.2, U1.7 (OUT)
SD3: C17.1, D17.2, D18.2, J1.23, R21.2, U2.7 (OUT)
SD4: C18.1, D19.2, D20.2, J1.17, R22.2, U3.7 (OUT)
SD5: C19.1, D21.2, D22.2, J1.16, R23.2, U4.7 (OUT)
SD6: C20.1, D23.2, D24.2, J1.20, R24.2, U5.7 (OUT)
SD7: J1.18
SW1: J4.7, R5.1, SW1.2 (B)
SW2: J4.8, R6.1, SW2.2 (B)
Start: C12.1, C15.1, J1.15, J2.10, R8.2
Tilt: C11.1, C14.1, J1.14, J2.9, R7.2
To Speaker: J1.4, J2.1
Vled: C5.1, C9.1, D8.1, J1.6, J2.3, R3.2
Vled Ret: C5.2, C9.2, D5.1, D8.2, J1.3, J2.2

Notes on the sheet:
REV B SOLENOID NOTE
OUT: U_S2_OUT->S2, U_S3_OUT->S3, U_S4_OUT->S4
drivers (one each for S2..S6)
with 5x TPS1H200A-Q1 smart high-side
Bring FAULT out; strap CL/DELAY per datasheet
CTRL: SD5->U_S5_IN, SD6->U_S6_IN
Each channel: local decoupling + FAULT testpoint
PLACEHOLDER MAP: U_S2..U_S6, one per channel
OUT: U_S5_OUT->S5, U_S6_OUT->S6; VIN=+22vdc
Replace Q10/Q11/Q18 discrete block
BOARD TO BOARD
CTRL: SD2->U_S2_IN, SD3->U_S3_IN, SD4->U_S4_IN

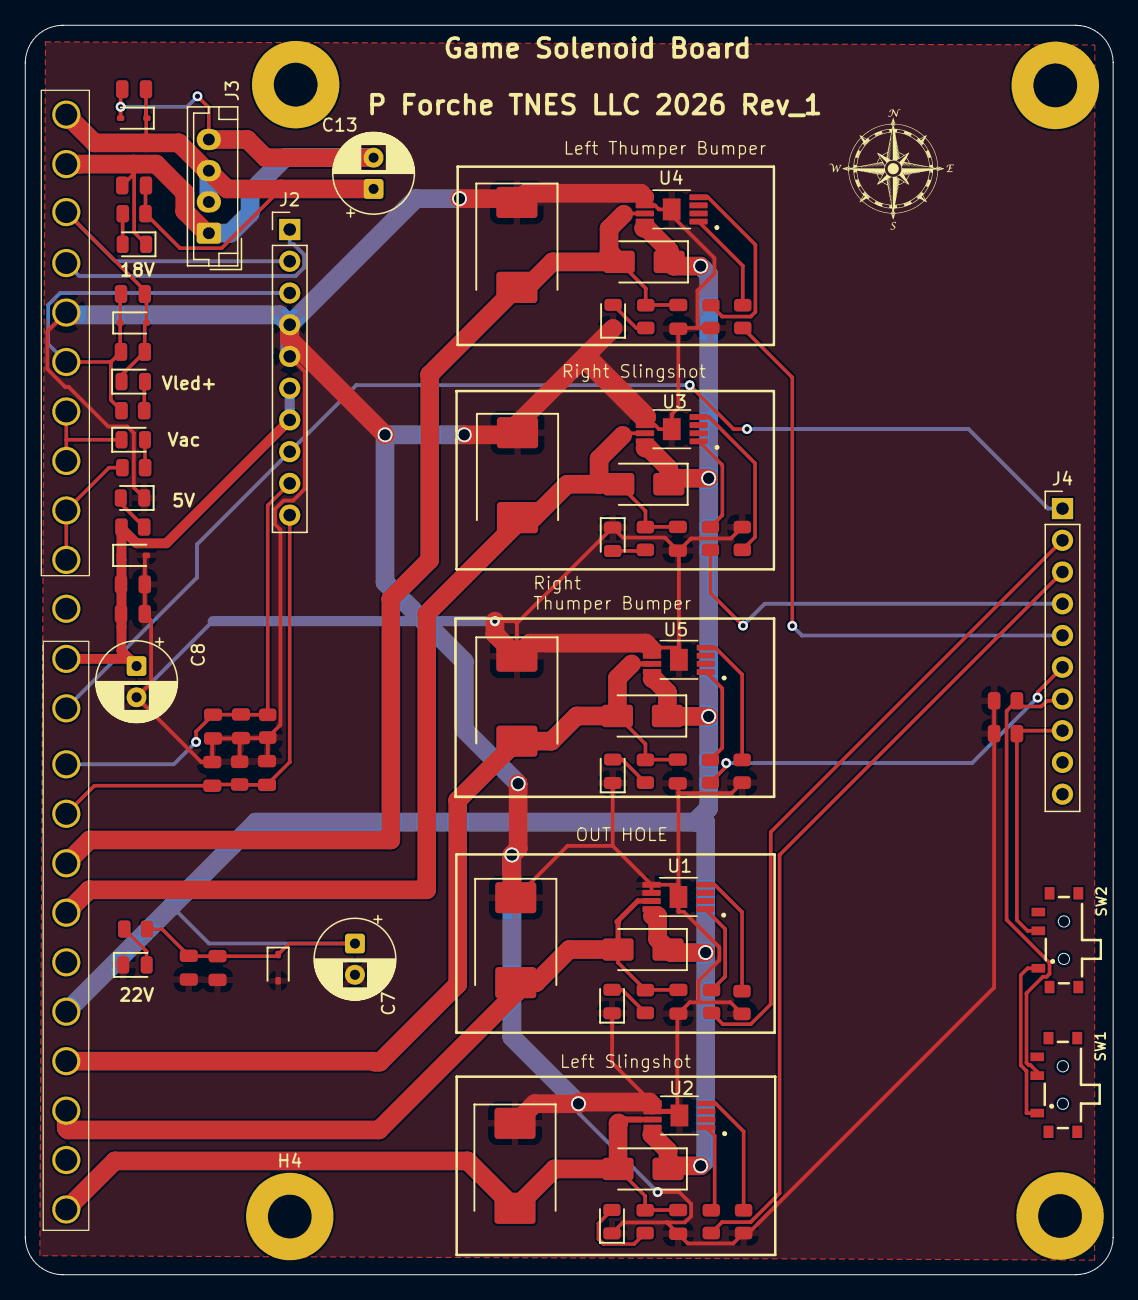
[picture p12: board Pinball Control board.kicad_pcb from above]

Board: 2 copper layers, 87.1 x 100.0 mm, 84 parts (0 on the bottom side), 46 nets.

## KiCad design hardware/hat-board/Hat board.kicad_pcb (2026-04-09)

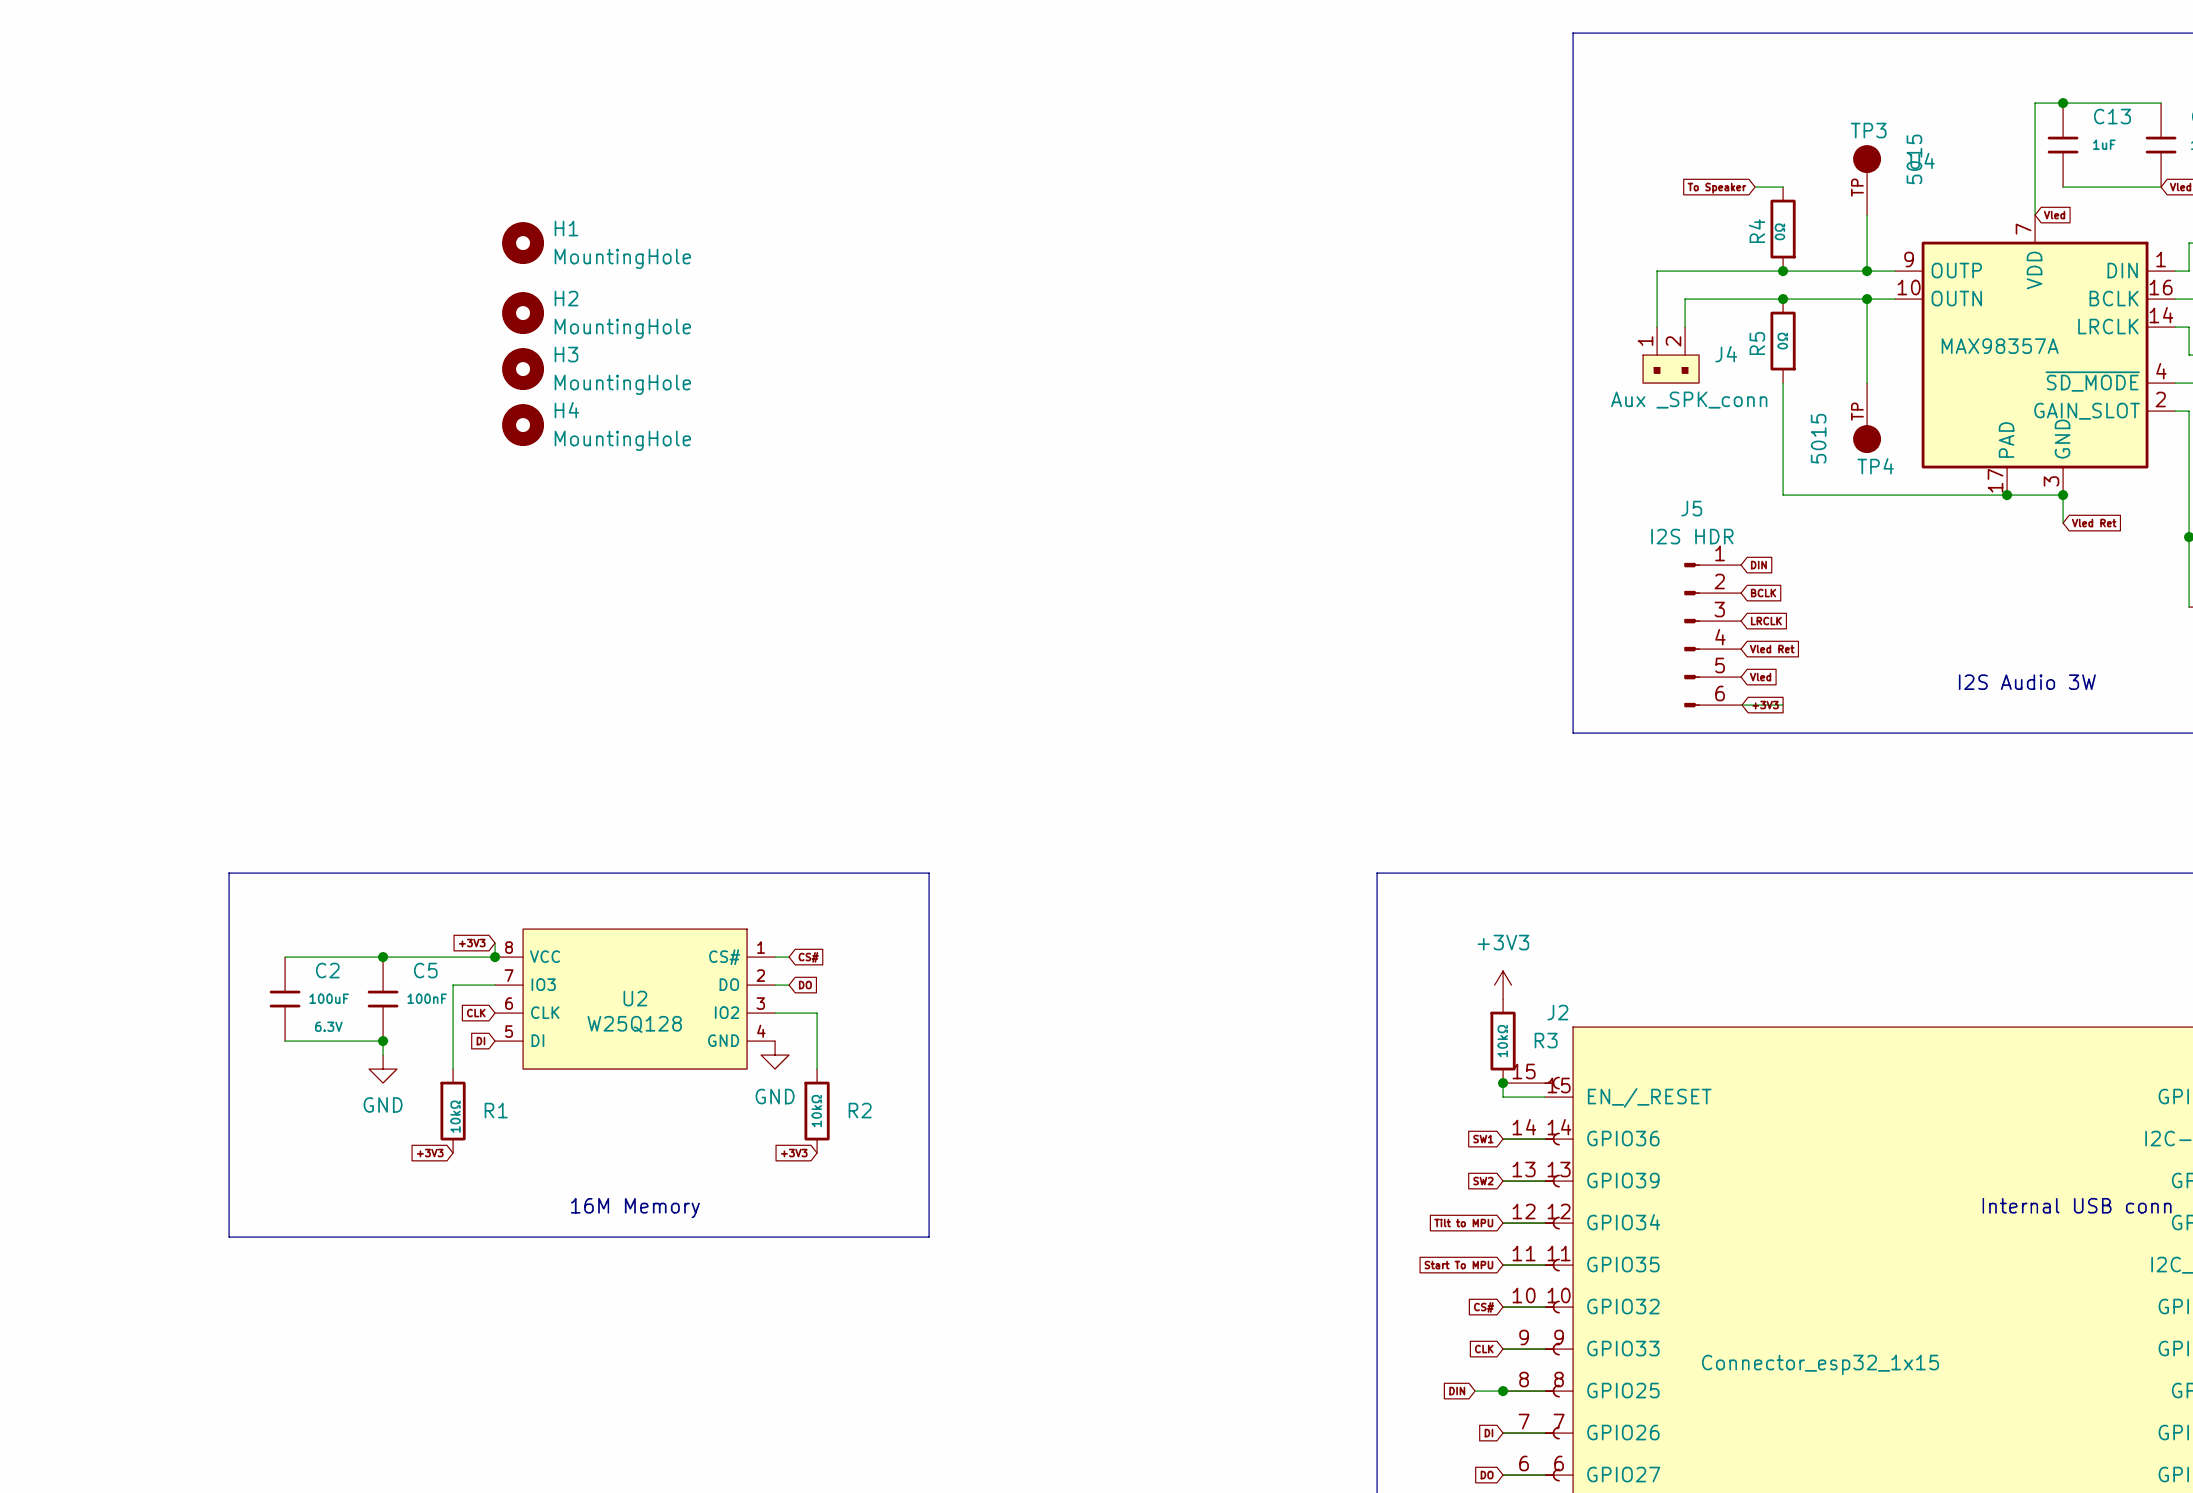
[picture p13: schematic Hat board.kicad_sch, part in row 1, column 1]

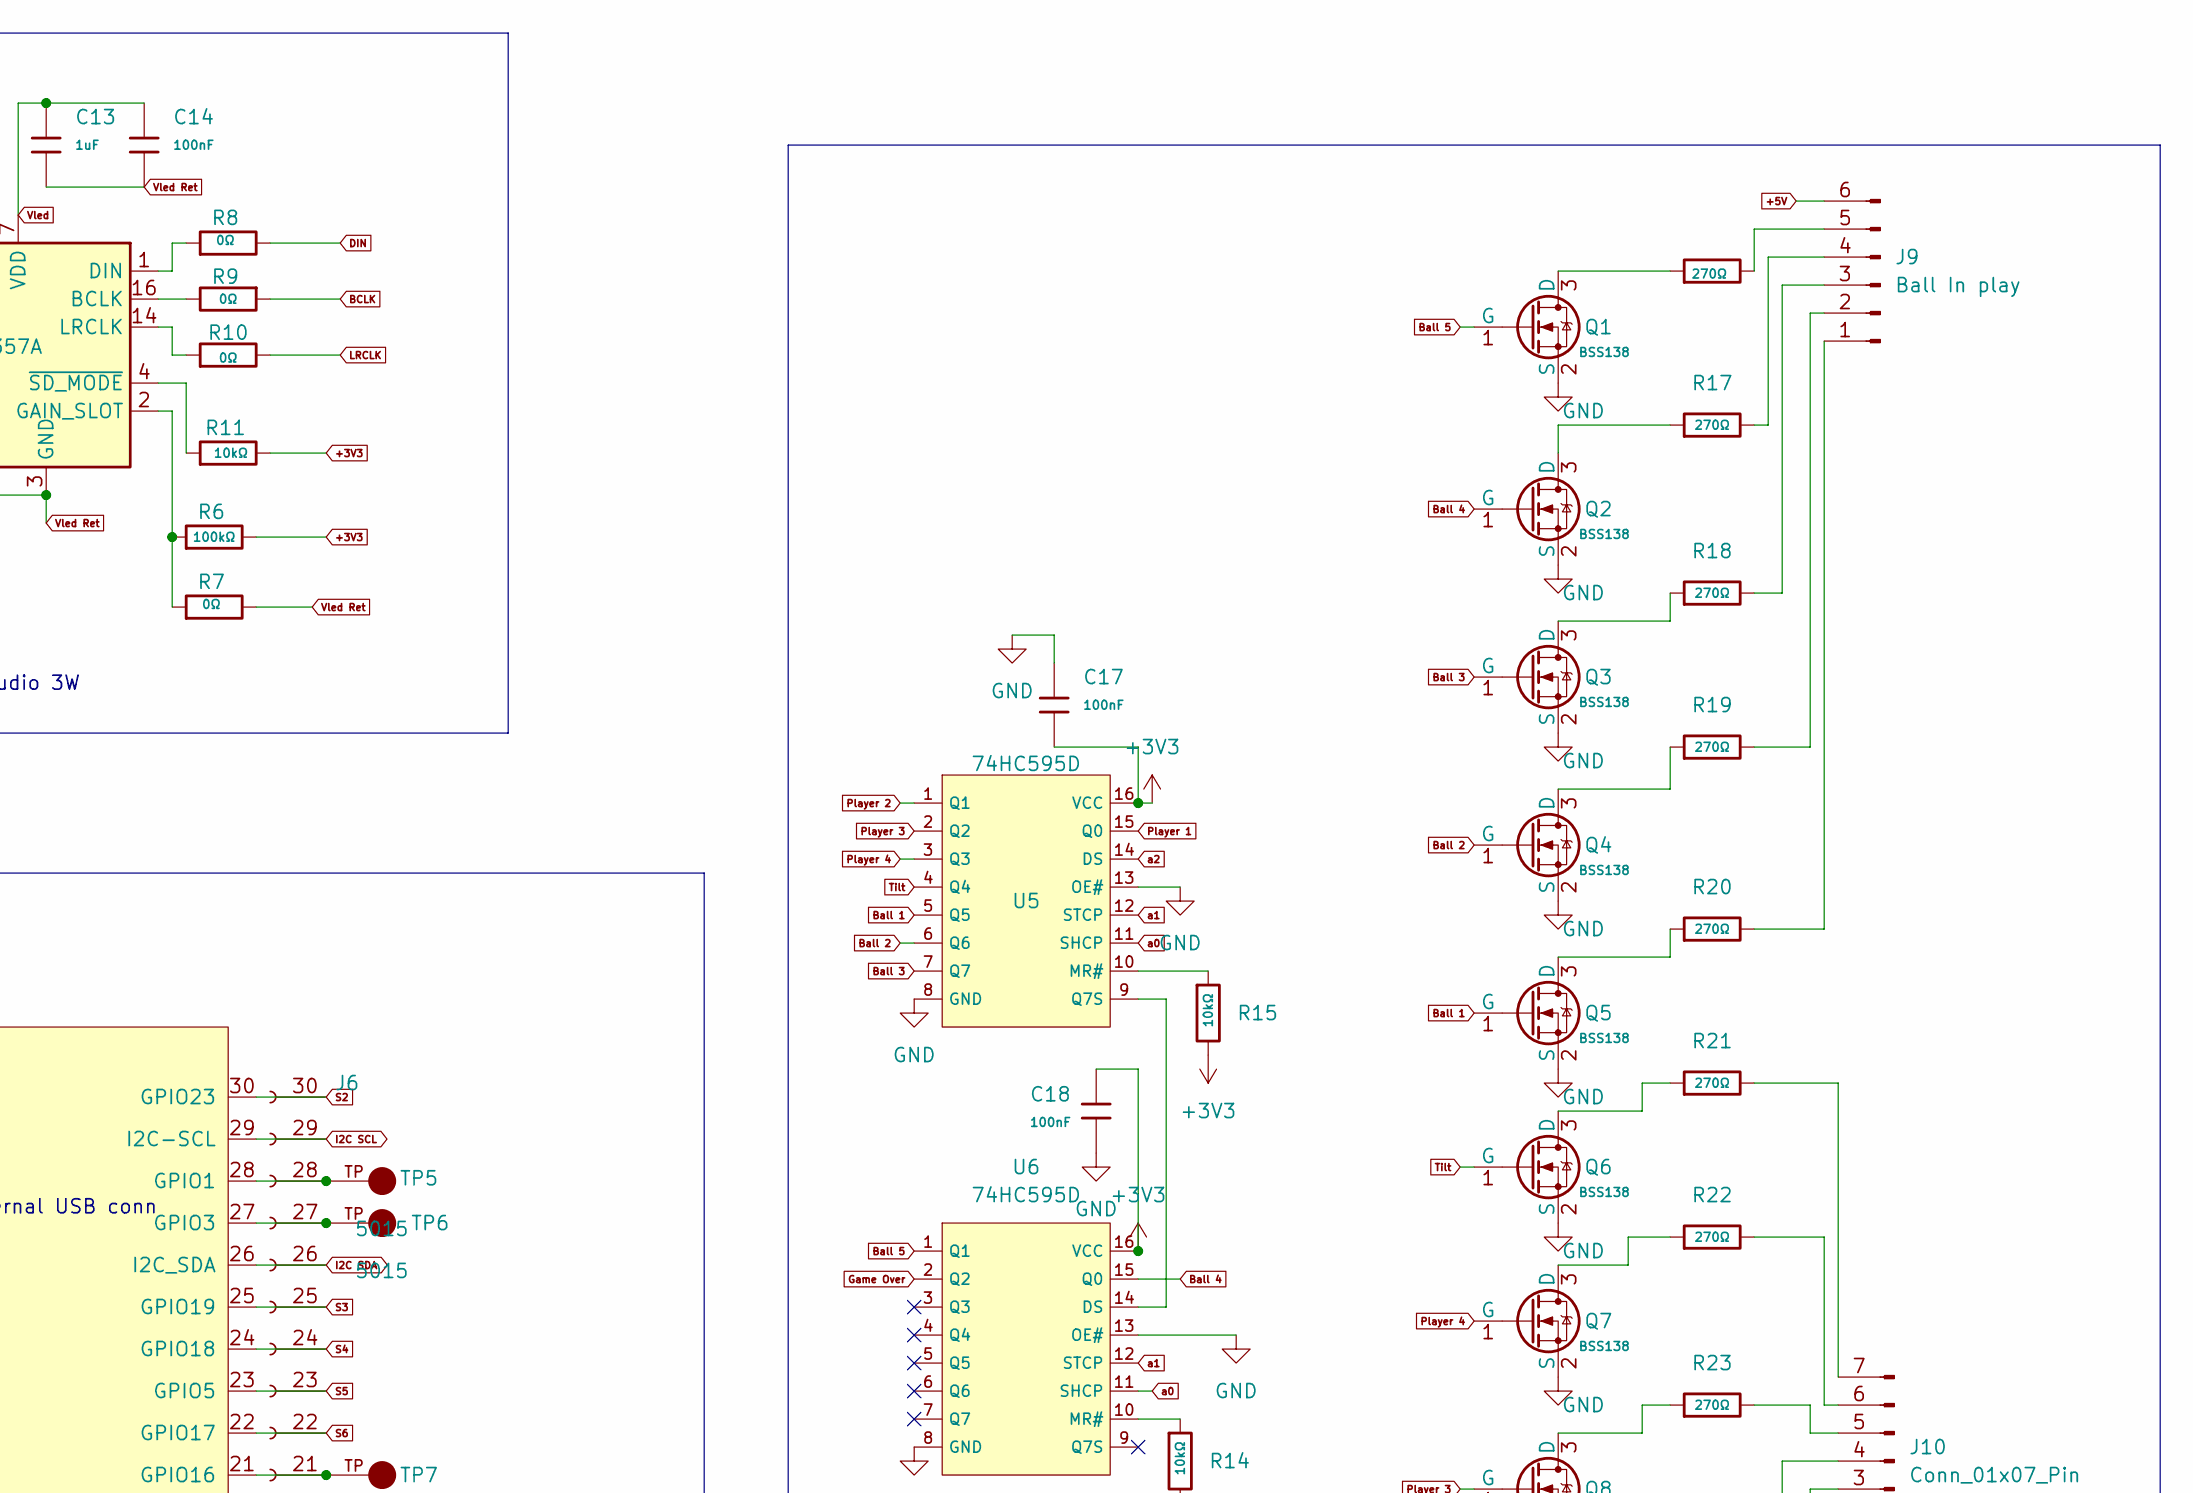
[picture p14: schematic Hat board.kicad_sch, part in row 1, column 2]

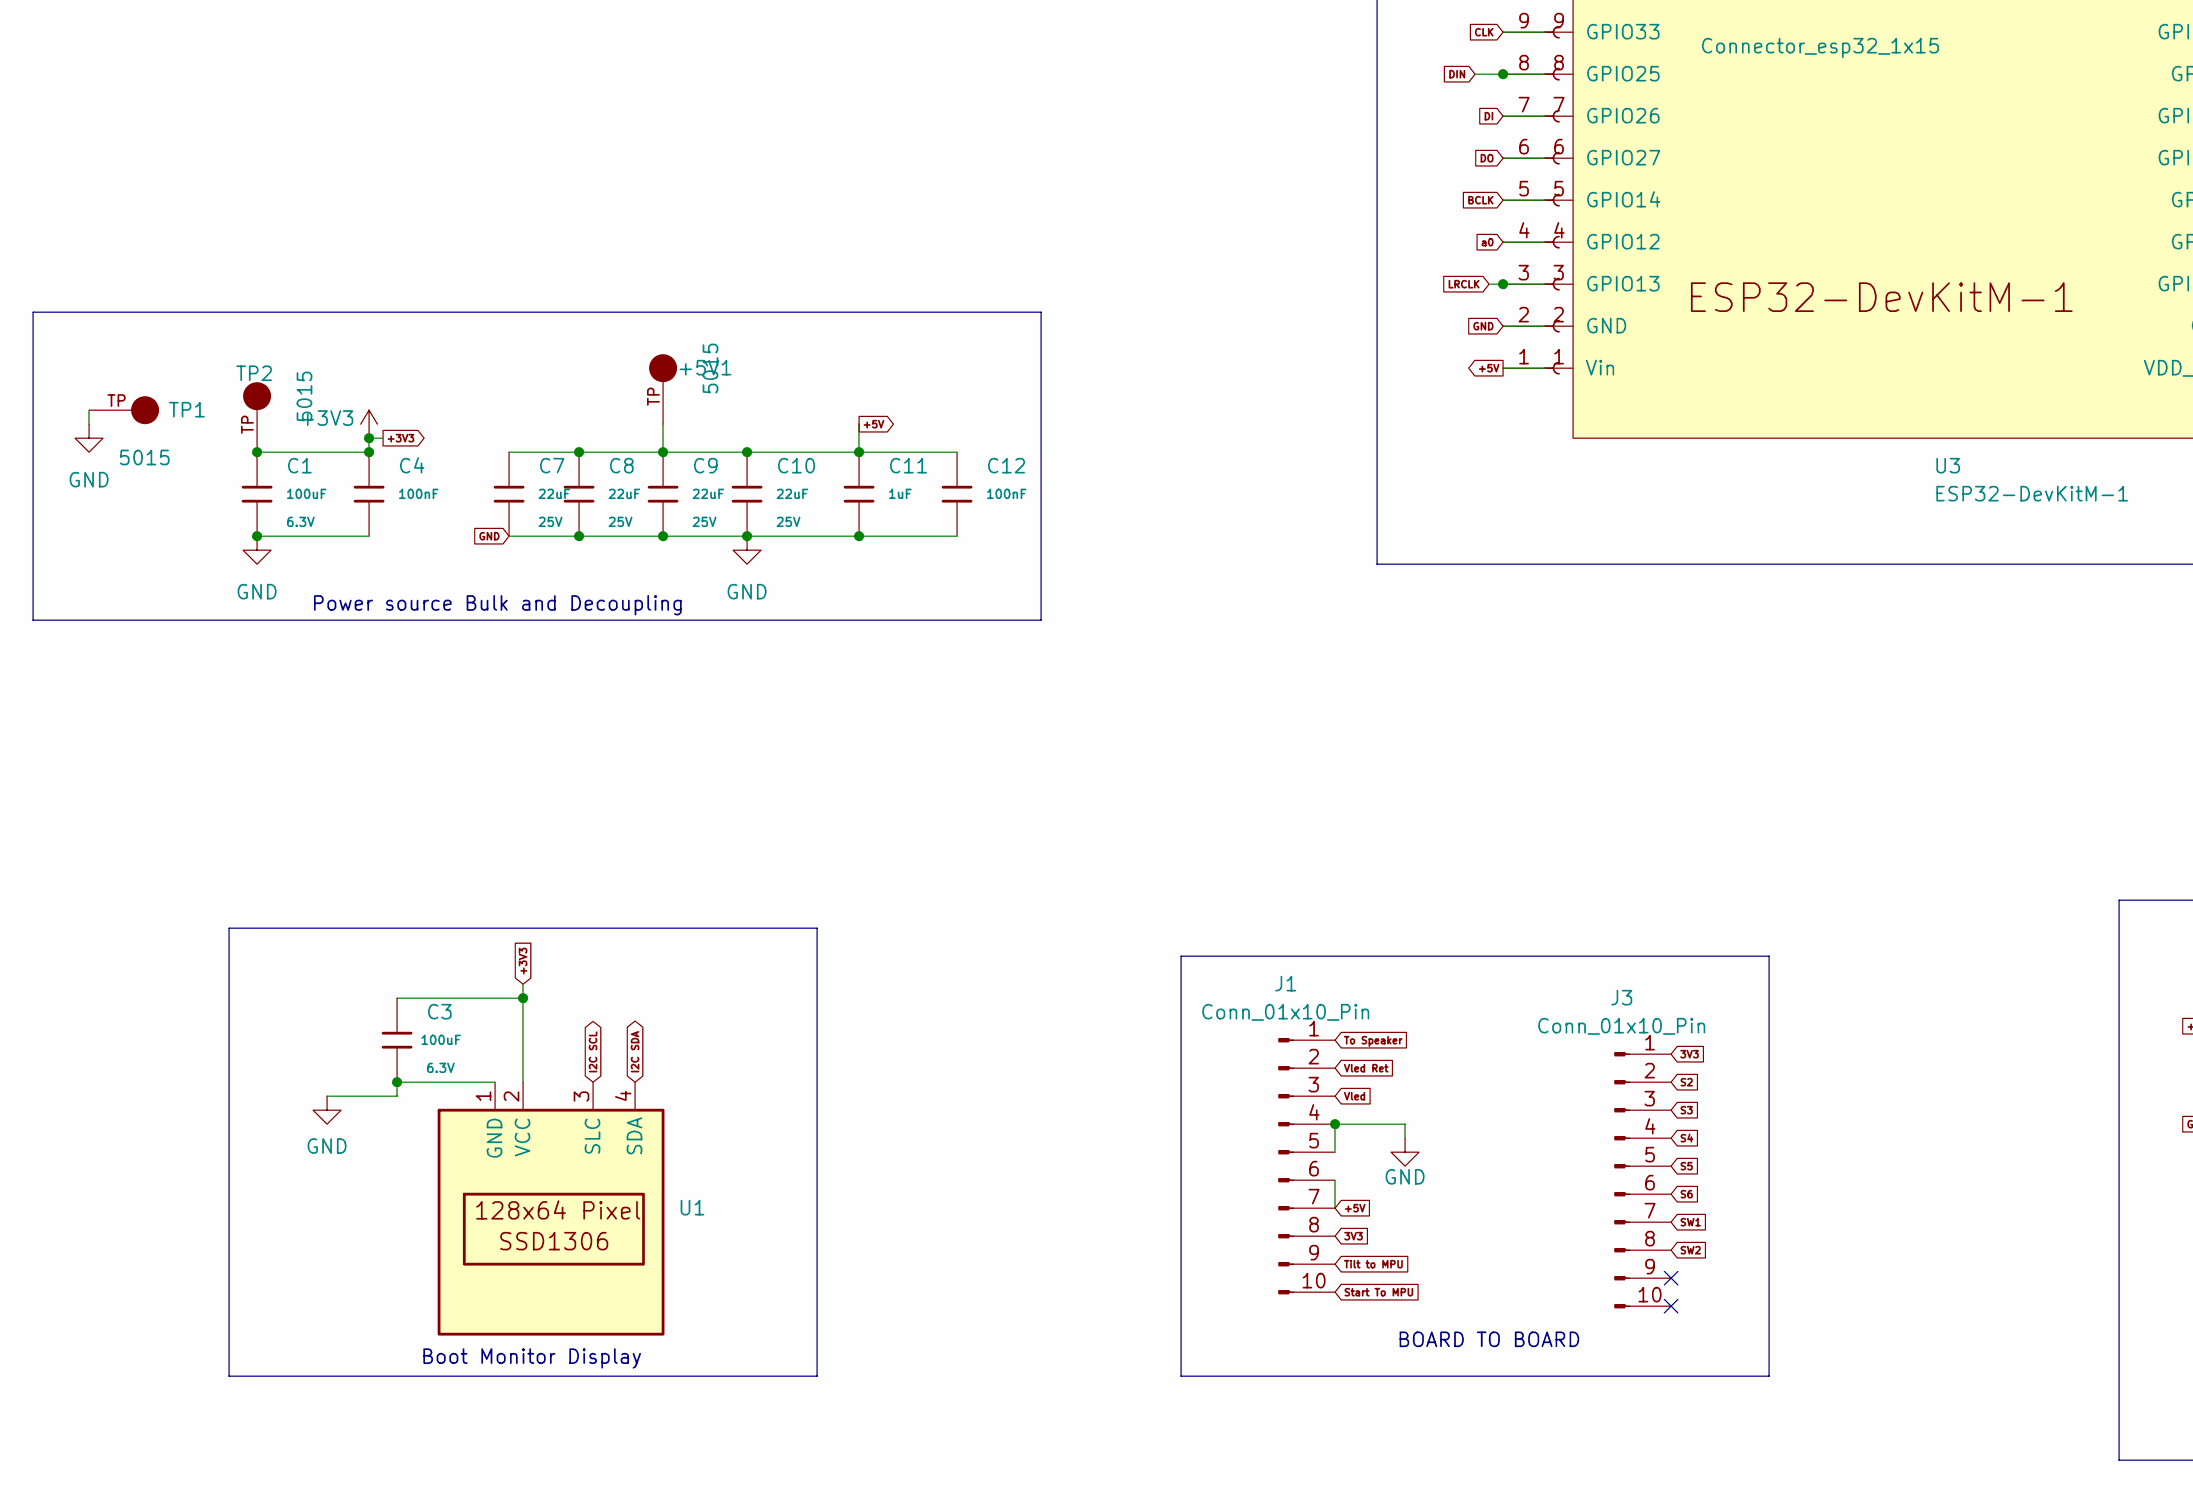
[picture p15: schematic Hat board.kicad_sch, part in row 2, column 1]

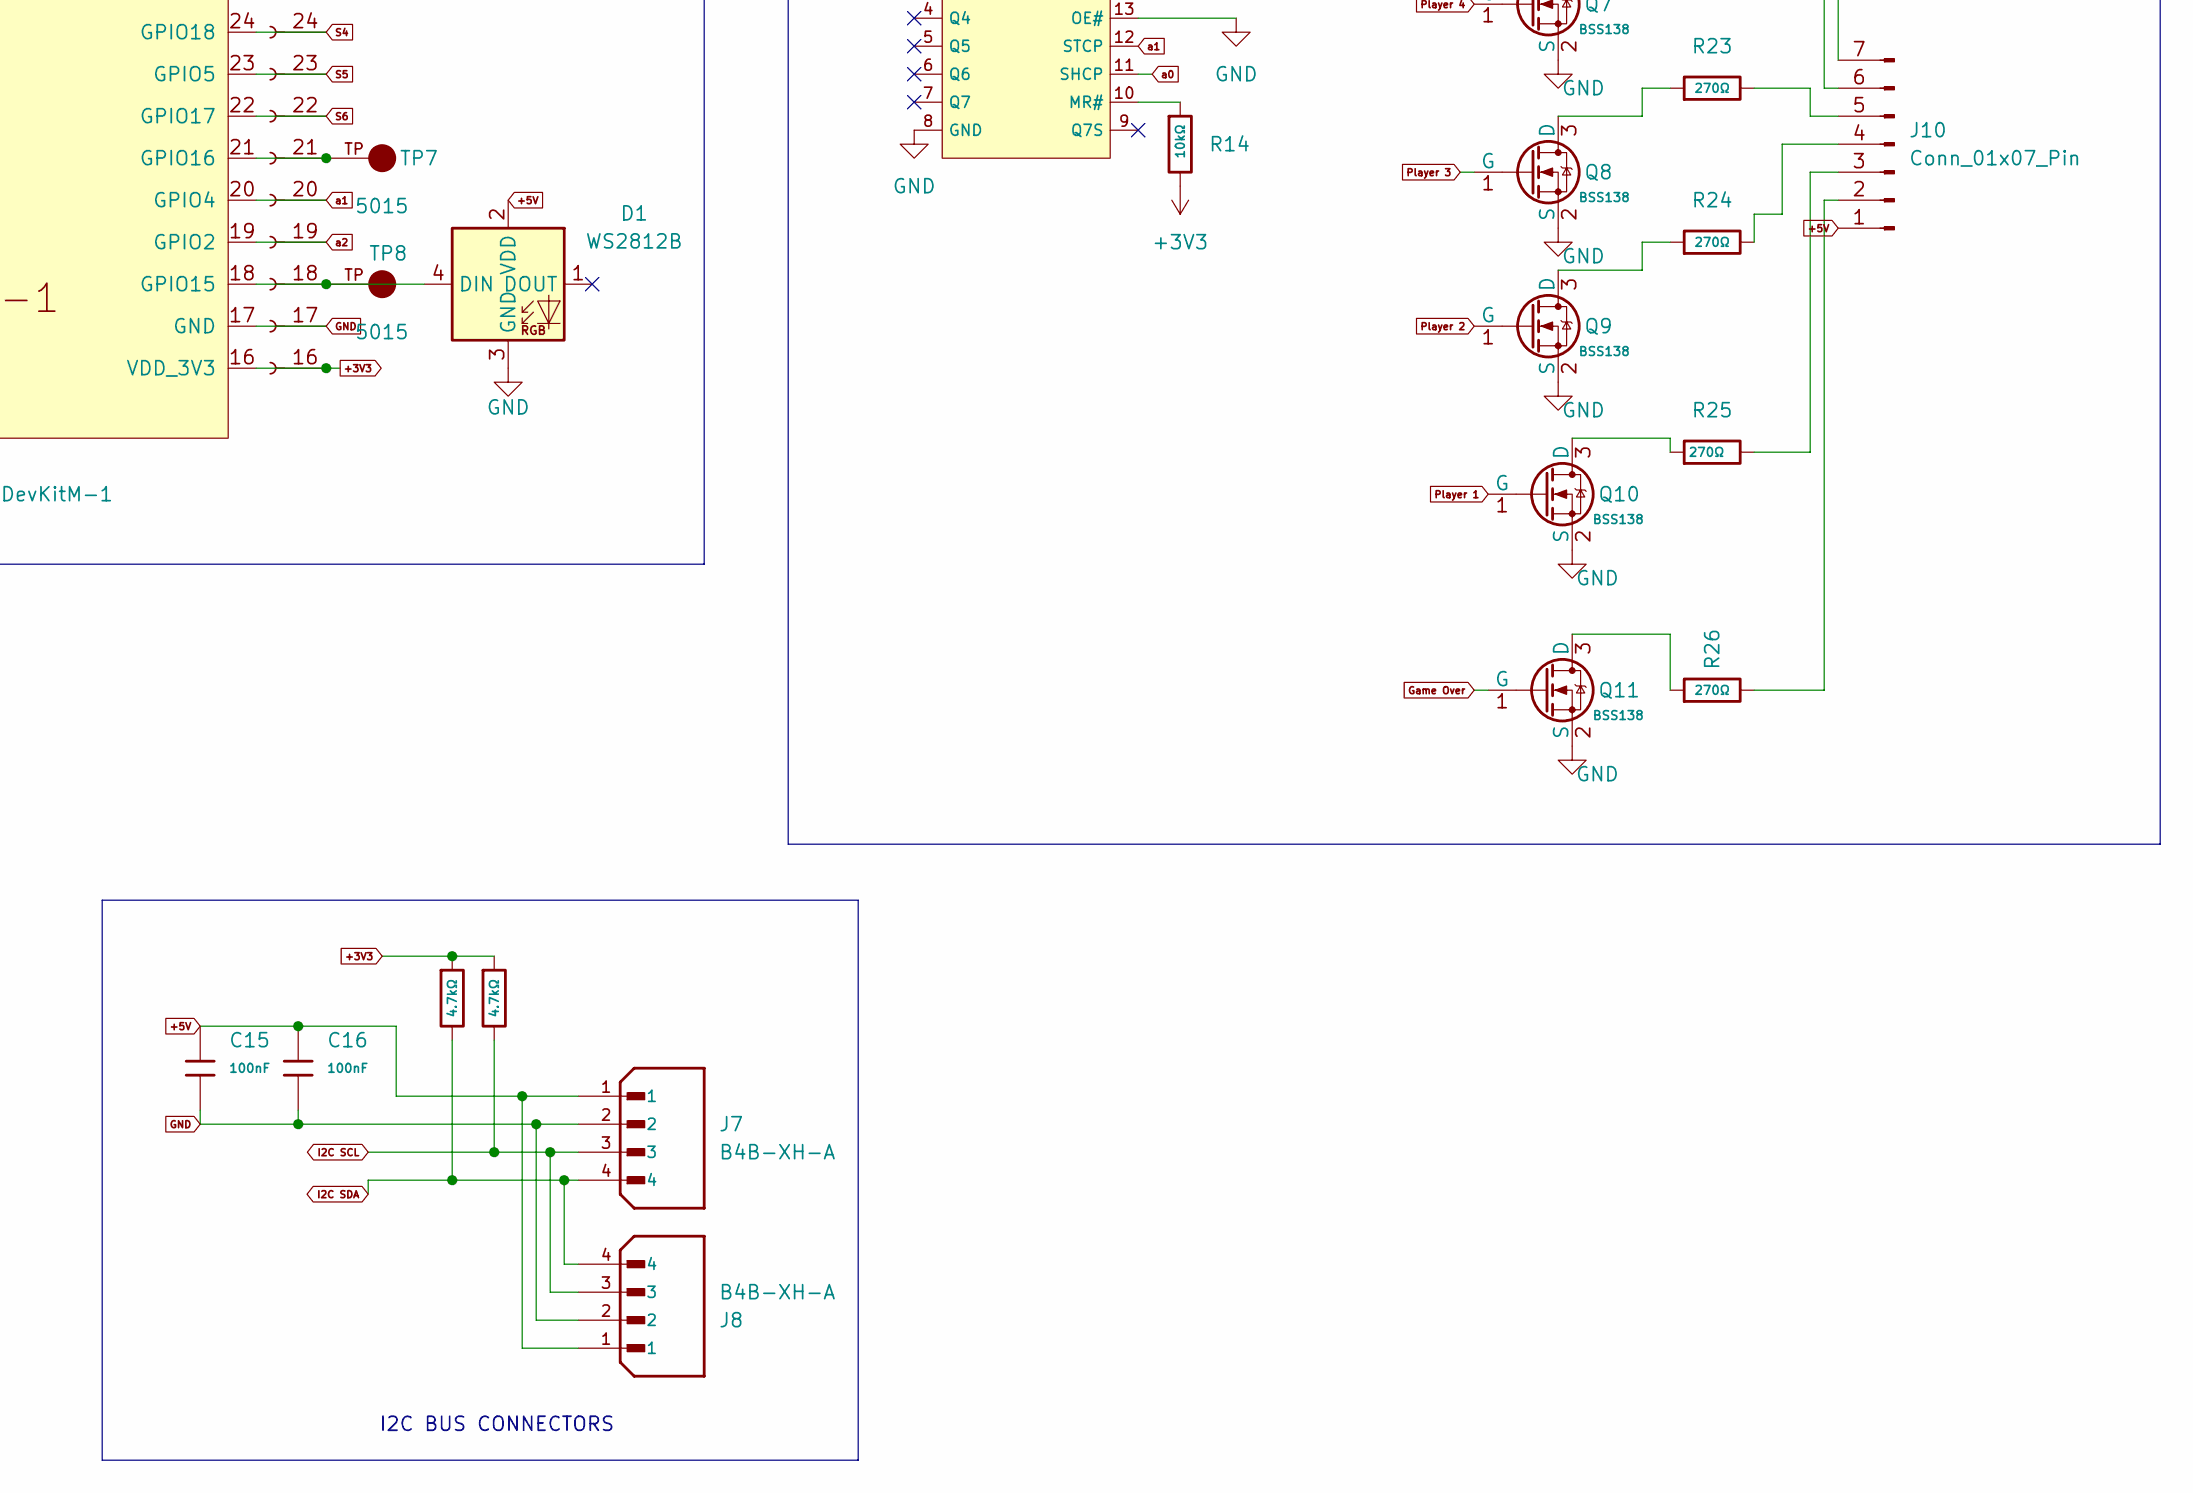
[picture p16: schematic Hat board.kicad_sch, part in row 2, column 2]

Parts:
+5V1: 5015; KEYSTONE_5015; MPN 5015; Digi-Key_PN 36-5015CT-ND
C1, C2, C3: 100uF; C_1206; Voltage Rated 6.3V; Tolerance ±20%; Part CL31A107MQHNNNE; LCSC C15008
C4, C5, C12, C14, C15, C16, C17, C18: 100nF; C_0805; Voltage Rated 50V; Tolerance ±10%; Part CC0805KRX7R9BB104; LCSC C49678
C7, C8, C9, C10: 22uF; C_0805; Voltage Rated 25V; Tolerance ±20%; Part CL21A226MAQNNNE; LCSC C45783
C11, C13: 1uF; C_0805; Voltage Rated 50V; Tolerance ±10%; Part CL21B105KBFNNNE; LCSC C28323
D1: WS2812B; LED-SMD_4P-L1.6-W1.5_XL-1615RGBC-WS2812B; LCSC C5349954
H1, H2, H3, H4: MountingHole; MountingHole_3.5mm_Pad
J1, J3: Conn_01x10_Pin; PinHeader_1x10_P2.54mm_Vertical
J2, J6: Connector_esp32_1x15; PinSocket_1x15_P2.54mm_Vertical
J4: Aux _SPK_conn; JST_XH_B2B-XH-A_1x02_P2.50mm_Vertical; MPN B2B-XH-A(LF)(SN); Digi-Key_PN 455-2247-ND
J5: I2S HDR; PinHeader_1x06_P2.54mm_Vertical_SMD_Pin1Right
J7, J8: B4B-XH-A; JST_EH_B4B-EH-A_1x04_P2.50mm_Vertical; PARTREV 7/4/21
J9: Ball In play; JST_XH_B6B-XH-AM_1x06_P2.50mm_Vertical
J10: Conn_01x07_Pin; JST_XH_B7B-XH-AM_1x07_P2.50mm_Vertical
Q1, Q2, Q3, Q4, Q5, Q6, Q7, Q8, Q9, Q10, Q11: BSS138; Q_SOT-23; Part BSS138; LCSC C7420339
R1, R2, R3, R11, R14, R15: 10kΩ; R_0805; Overload Voltage (Max) 150V; Tolerance ±1%; Part 0805W8F1002T5E; LCSC C17414
R4, R5, R7, R8, R9, R10: 0Ω; R_0805; Overload Voltage (Max) 150V; Tolerance ±1%; Part 0805W8F0000T5E; LCSC C17477
R6: 100kΩ; R_0805; Overload Voltage (Max) 150V; Tolerance ±1%; Part 0805W8F1003T5E; LCSC C149504
R12, R13: 4.7kΩ; R_0805; Overload Voltage (Max) 150V; Tolerance ±1%; Part 0805W8F4701T5E; LCSC C17673
R16, R17, R18, R19, R20, R21, R22, R23, R24, R25, R26: 270Ω; R_0805; Overload Voltage (Max) 150V; Tolerance ±1%; Part 0805W8F2700T5E; LCSC C17590
TP1, TP2, TP3, TP4, TP6, TP7, TP8: 5015; KEYSTONE_5015; MPN 5015; Digi-Key_PN 36-5015CT-ND
TP5: 5015; KEYSTONE_5015; Part 5015; LCSC C5199798
U1: ).96 inOLED display SSD1306
U2: W25Q128; SOIC-8_L5.3-W5.3-P1.27-LS8.0-BL; Part W25Q128JVSIQ; LCSC C97521
U3: ESP32-DevKitM-1
U4: MAX98357A; TQFN-16-1EP_3x3mm_P0.5mm_EP1.23x1.23mm
U5, U6: 74HC595D; SOIC-16_L9.9-W3.9-P1.27-LS6.0-BL; Supply Voltage 2V~6V; Part 74HC595D,118; LCSC C5947

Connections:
3V3: J1.8, J3.1
+3V3: C1.1, C2.1, C3.1, C4.1, C5.1, C17.2, C18.1, J5.6, J6.16 (VDD_3V3), R1.2, R2.2, R3.1, R6.2, R11.2, R12.1, R13.1, R14.2, R15.2, TP2.TP, U1.2 (VCC), U2.8 (VCC), U3.16 (VDD_3V3), U5.16 (VCC), U6.16 (VCC)
+5V: +5V1.TP, C7.1, C8.1, C9.1, C10.1, C11.1, C12.1, C15.1, C16.1, D1.2 (VDD), J1.6, J1.7, J2.1 (Vin), J7.1, J8.1, J9.6, J10.1, U3.1 (Vin)
BCLK: J2.5 (GPIO14), J5.2, R9.1, U3.5 (GPIO14)
Ball 1: Q5.1 (G), U5.5 (Q5)
Ball 2: Q4.1 (G), U5.6 (Q6)
Ball 3: Q3.1 (G), U5.7 (Q7)
Ball 4: Q2.1 (G), U6.15 (Q0)
Ball 5: Q1.1 (G), U6.1 (Q1)
CLK: J2.9 (GPIO33), U2.6 (CLK), U3.9 (GPIO33)
CS#: J2.10 (GPIO32), U2.1 (CS#), U3.10 (GPIO32)
DI: J2.7 (GPIO26), U2.5 (DI), U3.7 (GPIO26)
DIN: J2.8 (GPIO25), J5.1, R8.2, U3.8 (GPIO25)
DO: J2.6 (GPIO27), U2.2 (DO), U3.6 (GPIO27)
GND: C1.2, C2.2, C3.2, C4.2, C5.2, C7.2, C8.2, C9.2, C10.2, C11.2, C12.2, C15.2, C16.2, C17.1, C18.2, D1.3 (GND), H2.1, J1.4, J1.5, J2.2 (GND), J6.17 (GND), J7.2, J8.2, Q1.2 (S), Q2.2 (S), Q3.2 (S), Q4.2 (S), Q5.2 (S), Q6.2 (S), Q7.2 (S), Q8.2 (S), Q9.2 (S), Q10.2 (S), Q11.2 (S), TP1.TP, U1.1 (GND), U2.4 (GND), U3.2 (GND), U3.17 (GND), U5.8 (GND), U5.13 (OE#), U6.8 (GND), U6.13 (OE#)
Game Over: Q11.1 (G), U6.2 (Q2)
I2C SCL: J6.29 (I2C-SCL), J7.3, J8.3, R13.2, U1.3 (SLC), U3.29 (I2C-SCL)
I2C SDA: J6.26 (I2C_SDA), J7.4, J8.4, R12.2, U1.4 (SDA), U3.26 (I2C_SDA)
LRCLK: J2.3 (GPIO13), J5.3, R10.2, U3.3 (GPIO13)
unnamed: D1.4 (DIN), J6.18 (GPIO15), TP8.TP, U3.18 (GPIO15)
unnamed: J2.15 (EN_/_RESET), R3.2, U3.15 (EN_/_RESET)
unnamed: J6.28 (GPIO1), TP5.TP, U3.28 (GPIO1)
unnamed: J6.27 (GPIO3), TP6.TP, U3.27 (GPIO3)
unnamed: J6.21 (GPIO16), TP7.TP, U3.21 (GPIO16)
unnamed: J9.1, R20.2
unnamed: J9.2, R19.2
unnamed: J9.3, R18.2
unnamed: J9.4, R17.2
unnamed: J9.5, R16.2
unnamed: J10.2, R26.2
unnamed: J10.3, R25.2
unnamed: J10.4, R24.2
unnamed: J10.5, R23.2
unnamed: J10.6, R22.2
unnamed: J10.7, R21.2
unnamed: Q1.3 (D), R16.1
unnamed: Q2.3 (D), R17.1
unnamed: Q3.3 (D), R18.1
unnamed: Q4.3 (D), R19.1
unnamed: Q5.3 (D), R20.1
unnamed: Q6.3 (D), R21.1
unnamed: Q7.3 (D), R22.1
unnamed: Q8.3 (D), R23.1
unnamed: Q9.3 (D), R24.1
unnamed: Q10.3 (D), R25.1
unnamed: Q11.3 (D), R26.1
unnamed: R2.1, U2.3 (IO2)
unnamed: R1.1, U2.7 (IO3)
unnamed: R9.2, U4.16 (BCLK)
unnamed: R8.1, U4.1 (DIN)
unnamed: R6.1, R7.1, U4.2 (GAIN_SLOT)
unnamed: R10.1, U4.14 (LRCLK)
unnamed: J4.2, R5.2, TP4.TP, U4.10 (OUTN)
unnamed: J4.1, R4.1, TP3.TP, U4.9 (OUTP)
unnamed: R11.1, U4.4 (~SD_MODE)
unnamed: R15.1, U5.10 (MR#)
unnamed: U5.9 (Q7S), U6.14 (DS)
unnamed: R14.1, U6.10 (MR#)
Player 1: Q10.1 (G), U5.15 (Q0)
Player 2: Q9.1 (G), U5.1 (Q1)
Player 3: Q8.1 (G), U5.2 (Q2)
Player 4: Q7.1 (G), U5.3 (Q3)
S2: J3.2, J6.30 (GPIO23), U3.30 (GPIO23)
S3: J3.3, J6.25 (GPIO19), U3.25 (GPIO19)
S4: J3.4, J6.24 (GPIO18), U3.24 (GPIO18)
S5: J3.5, J6.23 (GPIO5), U3.23 (GPIO5)
S6: J3.6, J6.22 (GPIO17), U3.22 (GPIO17)
SW1: J2.14 (GPIO36), J3.7, U3.14 (GPIO36)
SW2: J2.13 (GPIO39), J3.8, U3.13 (GPIO39)
Start To MPU: J1.10, J2.11 (GPIO35), U3.11 (GPIO35)
Tilt: Q6.1 (G), U5.4 (Q4)
Tilt to MPU: J1.9, J2.12 (GPIO34), U3.12 (GPIO34)
To Speaker: J1.1, R4.2
Vled: C13.1, C14.1, J1.3, J5.5, U4.7 (VDD), U4.8 (VDD)
Vled Ret: C13.2, C14.2, J1.2, J5.4, R5.1, R7.2, U4.3 (GND), U4.11 (GND), U4.15 (GND), U4.17 (PAD)
a0: J2.4 (GPIO12), U3.4 (GPIO12), U5.11 (SHCP), U6.11 (SHCP)
a1: J6.20 (GPIO4), U3.20 (GPIO4), U5.12 (STCP), U6.12 (STCP)
a2: J6.19 (GPIO2), U3.19 (GPIO2), U5.14 (DS)

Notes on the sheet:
BOARD TO BOARD
Power source Bulk and Decoupling
I2C BUS CONNECTORS
Boot Monitor Display
16M Memory
Internal USB conn
I2S Audio 3W

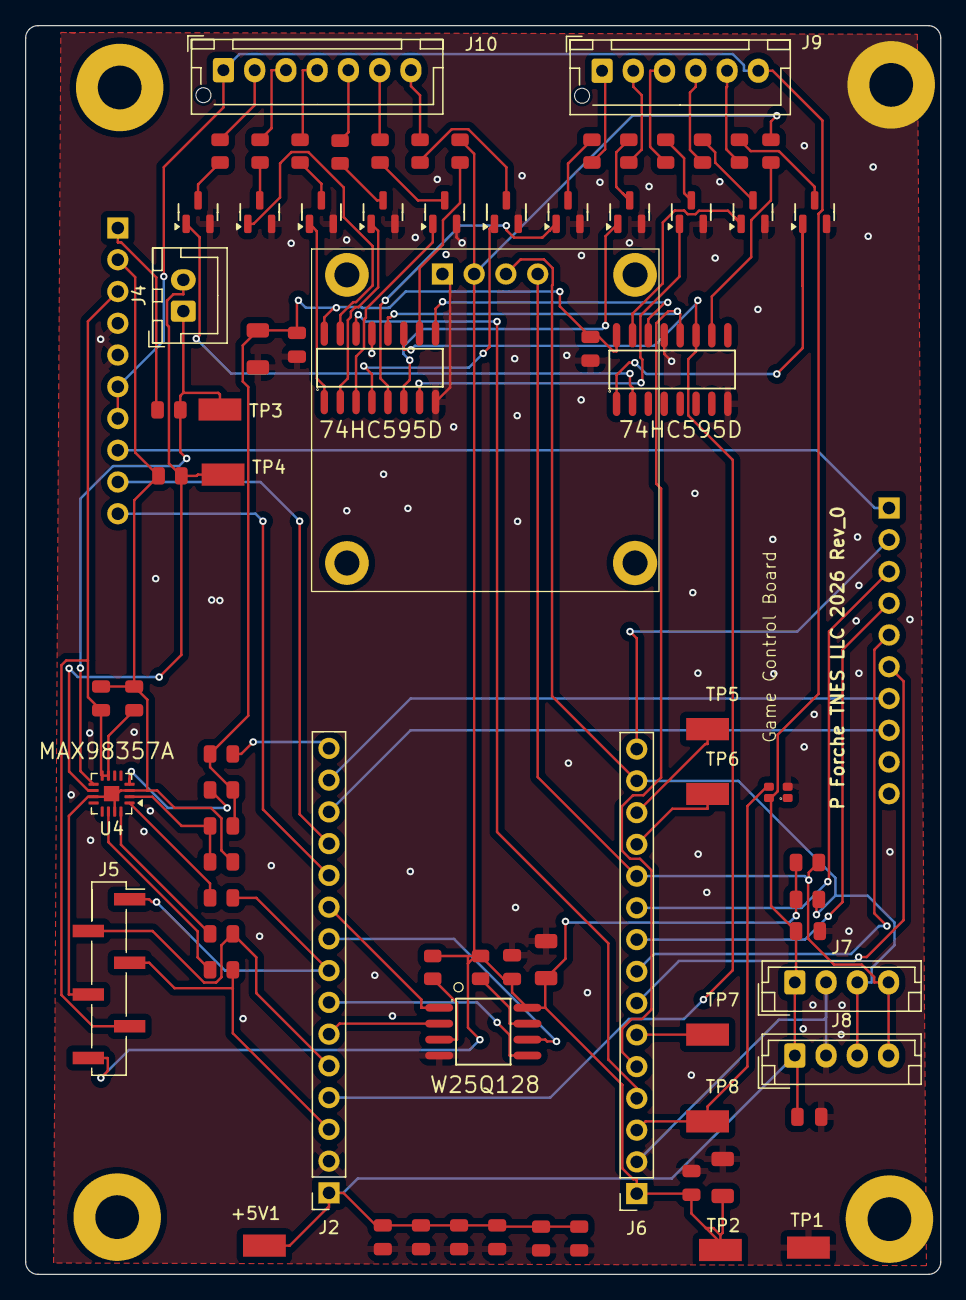
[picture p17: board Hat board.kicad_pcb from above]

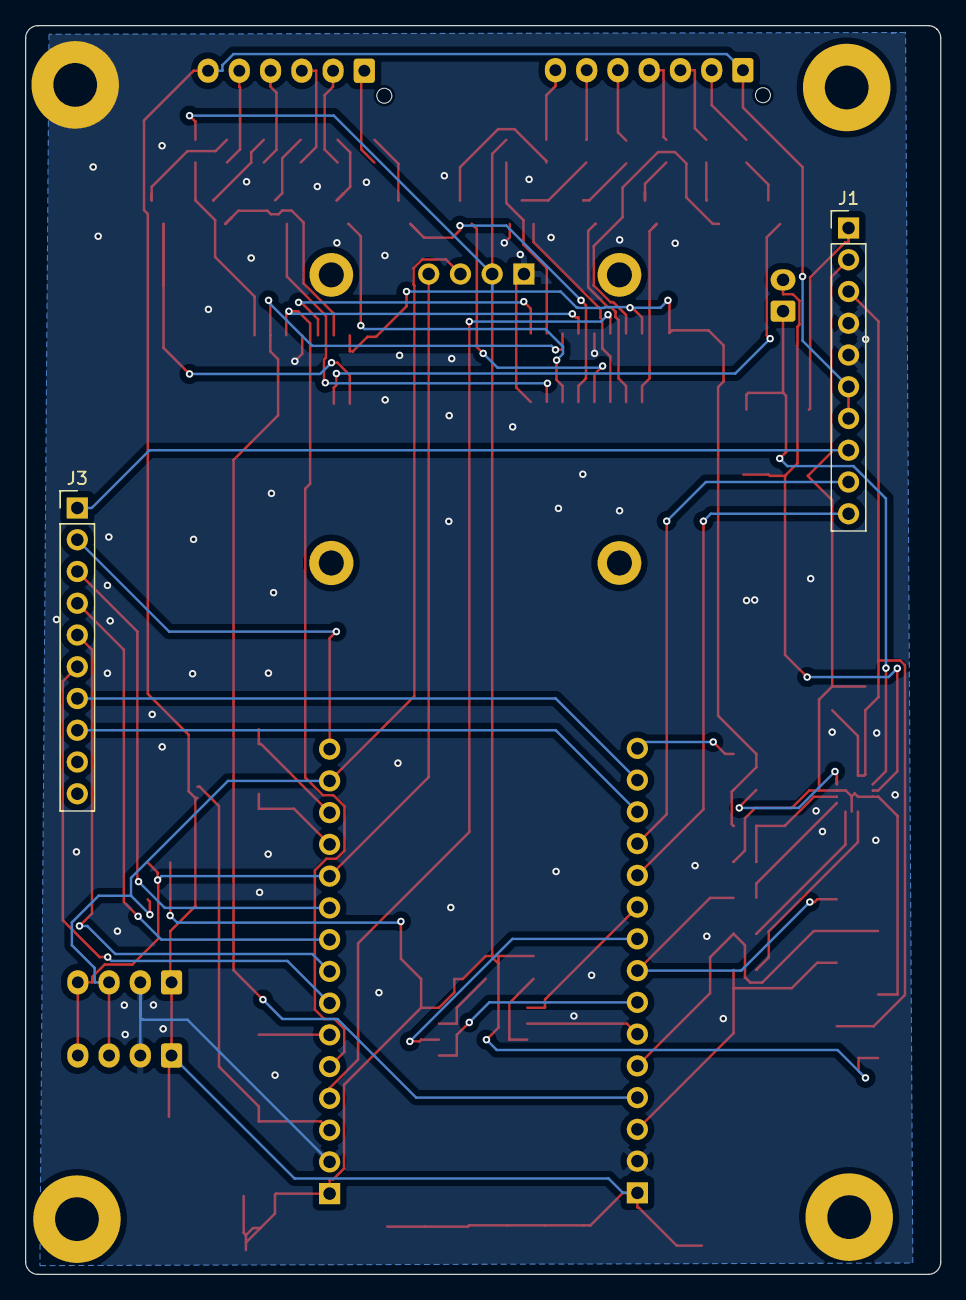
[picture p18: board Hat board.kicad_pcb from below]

Board: 2 copper layers, 73.2 x 99.9 mm, 83 parts (2 on the bottom side), 78 nets.

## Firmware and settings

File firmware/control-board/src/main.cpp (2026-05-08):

#include <Arduino.h>
#include <ctype.h>
#include <FS.h>
#include <SPI.h>
#include <SPIFFS.h>
#include <Wire.h>
#include <WiFi.h>
#include <Adafruit_GFX.h>
#include <Adafruit_SSD1306.h>
#include <Adafruit_NeoPixel.h>
#include <AudioFileSource.h>
#include <AudioFileSourceSPIFFS.h>
#include <AudioGeneratorMP3.h>
#include <AudioOutputI2S.h>
#include <SerialFlash.h>

#include "debug_oled_config.h"
#include "direct_input_config.h"
#include "direct_input_runtime.h"
#include "input_overlay_runtime.h"
#include "app_mode_config.h"
#include "audio_i2s_config.h"
#include "audio_runtime.h"
#include "board_protocol_runtime.h"
#include "captain_mapping.h"
#include "command_runtime.h"
#include "displays.h"
#include "external_flash_config.h"
#include "headbox_runtime.h"
#include "i2c_bus_config.h"
#include "matrix_interface_runtime.h"
#include "ota_config.h"
#include "ota_runtime.h"
#include "service_menu_runtime.h"
#include "solenoid_gpio_config.h"

void stopAudioPlaybackForOtaBridge();

namespace {
#ifndef CAPTAIN_SERIALFLASH_SPI_HZ
#define CAPTAIN_SERIALFLASH_SPI_HZ 8000000
#endif

#ifndef CAPTAIN_FW_VERSION
#define CAPTAIN_FW_VERSION "control-board"
#endif

#ifndef CAPTAIN_FW_BUILD_ID
#define CAPTAIN_FW_BUILD_ID "manual"
#endif

constexpr uint8_t HEARTBEAT_RGB_PIN = 15;
constexpr uint8_t HEARTBEAT_RGB_PIXELS = 1;
constexpr uint32_t HEARTBEAT_INTERVAL_MS = 500;
constexpr uint32_t DISPLAY_INTERVAL_MS = 250;
constexpr uint32_t INPUT_POLL_MS = 20;
constexpr uint32_t OUTPUT_TEST_INTERVAL_MS = 750;
constexpr uint32_t MATRIX_DEGRADED_WARN_INTERVAL_MS = 15000;
constexpr uint32_t MATRIX_OLED_STATUS_INTERVAL_MS = 3000;
constexpr uint32_t MATRIX_SWITCH_LOG_DEBOUNCE_MS = 700;
constexpr uint32_t MATRIX_SWITCH_LOG_REPORT_MS = 5000;
constexpr uint32_t MATRIX_SWITCH_LOG_MAX_PER_REPORT = 20;
constexpr uint8_t MATRIX_ROWS = 8;
constexpr uint8_t MATRIX_COLS = 4;
constexpr uint8_t OUTPUT_TEST_SINGLE_SOLENOID = SOLENOID_S2;
constexpr uint8_t MATRIX_LAMP_TEST_COUNT = 5;
constexpr uint8_t MATRIX_LAMP_TEST_ROWS[MATRIX_LAMP_TEST_COUNT] = {0, 1, 2, 3, 4};
constexpr uint8_t MATRIX_LAMP_TEST_COL = 1;
constexpr float CAPTAIN_AUDIO_MP3_GAIN = 0.12f;

// System vs test behavior is selected by CAPTAIN_APP_MODE_TEST build flag.
constexpr bool CAPTAIN_ENABLE_OUTPUT_TEST = CAPTAIN_ENABLE_OUTPUT_TEST_DEFAULT;

bool heartbeatState = false;
uint32_t lastHeartbeatMs = 0;
uint32_t lastDisplayMs = 0;
uint32_t lastOutputTestMs = 0;
uint32_t solenoidPulseEndMs = 0;  // Track when current pulse should end (real pulse timing)
uint32_t lastMatrixDegradedWarnMs = 0;
uint32_t lastMatrixOledStatusMs = 0;
uint32_t lastMatrixSwitchSuppressedReportMs = 0;
uint32_t displayCounter = 0;
uint32_t matrixSwitchSuppressedCount = 0;
uint32_t matrixSwitchRateLimitedCount = 0;
uint32_t matrixSwitchLoggedCount = 0;
int8_t activeOutput = -1;
bool matrixLampBlinkOn = false;
bool matrixLinkHealthyLast = false;
uint32_t matrixSwitchLastLoggedMs[MATRIX_ROWS][MATRIX_COLS] = {};
uint16_t matrixSwitchSuppressedByCell[MATRIX_ROWS][MATRIX_COLS] = {};
captain::headbox::Runtime headboxRuntime = {};
captain::ota::Runtime otaRuntime = {};
captain::audio::Runtime audioRuntime = {};
captain::matrix::Runtime matrixRuntime = {};
captain::protocol::Runtime protocolRuntime = {};
captain::service::Runtime serviceRuntime = {};
captain::input::overlay::Runtime inputOverlayRuntime = {};
Adafruit_SSD1306 debugOled(CAPTAIN_DEBUG_OLED_WIDTH, CAPTAIN_DEBUG_OLED_HEIGHT, &Wire, CAPTAIN_DEBUG_OLED_RESET_PIN);
Adafruit_NeoPixel* heartbeatRgb = nullptr;
bool debugOledReady = false;
uint8_t debugOledAddress = CAPTAIN_DEBUG_OLED_I2C_ADDRESS_PRIMARY;

void writeDebugOledStatus(const char* line1, const char* line2 = nullptr, const char* line3 = nullptr);
void updateOtaStatus(const char* line1, const char* line2, const char* line3);
void updateOnboardDisplayForOtaStatus(const char* line1, const char* line2, const char* line3);
void onMatrixSwitchEdge(uint8_t row, uint8_t col, bool closed, uint32_t nowMs);
void updateMatrixDiagnostics(uint32_t nowMs);

uint32_t fnv1a32(const char* text) {
    uint32_t hash = 2166136261UL;
    if (text == nullptr) {
        return hash;
    }
    for (const char* p = text; *p != '\0'; ++p) {
        hash ^= static_cast<uint8_t>(*p);
        hash *= 16777619UL;
    }
    return hash;
}

int8_t parsePercentFromStatusText(const char* text) {
    if (text == nullptr) {
        return -1;
    }

    const char* percentMark = strchr(text, '%');
    if (percentMark == nullptr) {
        return -1;
    }

    const char* begin = percentMark;
    while (begin > text && isdigit(static_cast<unsigned char>(*(begin - 1)))) {
        begin--;
    }

    if (begin == percentMark) {
        return -1;
    }

    int value = 0;
    for (const char* cursor = begin; cursor < percentMark; cursor++) {
        value = (value * 10) + (*cursor - '0');
    }

    if (value < 0) {
        value = 0;
    }
    if (value > 100) {
        value = 100;
    }
    return static_cast<int8_t>(value);
}

void drawWifiIconOnDebugOled(bool connected) {
    const int x = 116;
    const int y = 2;
    const uint16_t color = connected ? SSD1306_WHITE : SSD1306_BLACK;

    debugOled.drawCircle(x + 5, y + 8, 6, color);
    debugOled.drawCircle(x + 5, y + 8, 4, color);
    debugOled.fillCircle(x + 5, y + 8, connected ? 1 : 0, SSD1306_WHITE);

    if (!connected) {
        debugOled.drawLine(x, y + 13, x + 10, y + 3, SSD1306_WHITE);
    }
}

void drawProgressBarOnDebugOled(int8_t percent) {
    if (percent < 0) {
        return;
    }

    constexpr int BAR_X = 4;
    constexpr int BAR_Y = 56;
    constexpr int BAR_W = 120;
    constexpr int BAR_H = 7;

    const int fillWidth = (BAR_W - 2) * percent / 100;
    debugOled.drawRect(BAR_X, BAR_Y, BAR_W, BAR_H, SSD1306_WHITE);
    debugOled.fillRect(BAR_X + 1, BAR_Y + 1, fillWidth, BAR_H - 2, SSD1306_WHITE);
}

void updateIdleOledStatus(uint32_t now) {
    if (!debugOledReady) {
        return;
    }

    captain::input::overlay::updateIdle(inputOverlayRuntime, now, otaRuntime.inProgress, writeDebugOledStatus);
}

void updateOnboardDisplayForOtaStatus(const char* line1, const char* line2, const char* line3) {
    const bool wifiConnected = WiFi.status() == WL_CONNECTED;
    char text[6] = {};

    if (line1 == nullptr) {
        displayStatusMessage("OTA", wifiConnected);
        return;
    }

    if (strcmp(line1, "OTA WiFi connect") == 0) {
        displayStatusMessage("WAIT", false);
        return;
    }

    if (strcmp(line1, "OTA WiFi ready") == 0) {
        displayStatusMessage("READY", true);
        return;
    }

    if (strcmp(line1, "OTA download") == 0) {
        unsigned long percent = 0;
        if (line2 != nullptr && sscanf(line2, "DL %lu%%", &percent) == 1) {
            snprintf(text, sizeof(text), "D%03lu", percent > 999UL ? 999UL : percent);
            displayStatusMessage(text, wifiConnected);
        } else {
            displayStatusMessage("DOWN", wifiConnected);
        }
        return;
    }

    if (strcmp(line1, "OTA flashing") == 0) {
        unsigned long percent = 0;
        if (line2 != nullptr && sscanf(line2, "FL %lu%%", &percent) == 1) {
            snprintf(text, sizeof(text), "F%03lu", percent > 999UL ? 999UL : percent);
            displayStatusMessage(text, wifiConnected);
        } else {
            displayStatusMessage("FLASH", wifiConnected);
        }
        return;
    }

    if (strcmp(line1, "OTA stage ready") == 0) {
        displayStatusMessage("STAGE", wifiConnected);
        return;
    }

    if (strcmp(line1, "OTA success") == 0) {
        displayStatusMessage("DONE", wifiConnected);
        return;
    }

    if (strcmp(line1, "OTA busy") == 0) {
        displayStatusMessage("BUSY", wifiConnected);
        return;
    }

    if (strstr(line1, "fail") != nullptr ||
        strstr(line1, "missing") != nullptr ||
        strstr(line1, "down") != nullptr) {
        displayStatusMessage("FAIL", wifiConnected);
        return;
    }

    if (strcmp(line1, "OTA autostart") == 0) {
        displayStatusMessage("AUTO", wifiConnected);
        return;
    }

    if (strcmp(line1, "OTA creds updated") == 0) {
        displayStatusMessage("WIFI", wifiConnected);
        return;
    }

    if (line3 != nullptr && strstr(line3, "waiting") != nullptr) {
        displayStatusMessage("WAIT", wifiConnected);
        return;
    }

    displayStatusMessage("OTA", wifiConnected);
}

void updateOtaStatus(const char* line1, const char* line2, const char* line3) {
    writeDebugOledStatus(line1 != nullptr ? line1 : "OTA", line2, line3);
    updateOnboardDisplayForOtaStatus(line1, line2, line3);
}

void setHeartbeatColor(uint8_t red, uint8_t green, uint8_t blue) {
    if (heartbeatRgb == nullptr) {
        return;
    }

    heartbeatRgb->setPixelColor(0, heartbeatRgb->Color(red, green, blue));
    heartbeatRgb->show();
}

void runHeartbeatStartupCycle() {
    setHeartbeatColor(32, 0, 0);
    delay(180);
    setHeartbeatColor(0, 32, 0);
    delay(180);
    setHeartbeatColor(0, 0, 32);
    delay(180);
    setHeartbeatColor(0, 0, 0);
}


bool probeI2CAddress(uint8_t address) {
    Wire.beginTransmission(address);
    return Wire.endTransmission() == 0;
}

void scanI2CBus() {
    Serial.println("I2C scan start");
    uint8_t foundCount = 0;
    for (uint8_t address = 1; address < 127; address++) {
        if (!probeI2CAddress(address)) {
            continue;
        }

        foundCount++;
        Serial.printf("  found I2C device at 0x%02X\n", address);
    }

    if (foundCount == 0) {
        Serial.println("  no I2C devices detected");
    }
}

void reportDebugOledStatus() {
    if (!CAPTAIN_DEBUG_OLED_ENABLED) {
        Serial.println("Debug OLED support disabled");
        return;
    }

    const bool primaryFound = probeI2CAddress(CAPTAIN_DEBUG_OLED_I2C_ADDRESS_PRIMARY);
    const bool secondaryFound = probeI2CAddress(CAPTAIN_DEBUG_OLED_I2C_ADDRESS_SECONDARY);

    Serial.printf("Debug OLED expected size: %ux%u\n",
                  static_cast<unsigned>(CAPTAIN_DEBUG_OLED_WIDTH),
                  static_cast<unsigned>(CAPTAIN_DEBUG_OLED_HEIGHT));

    if (primaryFound || secondaryFound) {
        Serial.printf("Debug OLED detected at %s%s%s\n",
                      primaryFound ? "0x3C" : "",
                      (primaryFound && secondaryFound) ? " and " : "",
                      secondaryFound ? "0x3D" : "");
    } else {
        Serial.println("Debug OLED not detected at 0x3C/0x3D; confirm wiring and address");
    }
}

void writeDebugOledStatus(const char* line1, const char* line2, const char* line3) {
    if (!debugOledReady) {
        return;
    }

    debugOled.clearDisplay();
    debugOled.setTextSize(1);
    debugOled.setTextColor(SSD1306_WHITE);
    debugOled.drawLine(0, 14, 127, 14, SSD1306_WHITE);
    debugOled.setCursor(0, 2);
    debugOled.print(F("Captain Ctrl"));

    if (line1 != nullptr) {
        debugOled.setCursor(0, 20);
        debugOled.print(line1);
    }
    if (line2 != nullptr) {
        debugOled.setCursor(0, 33);
        debugOled.print(line2);
    }
    if (line3 != nullptr) {
        debugOled.setCursor(0, 46);
        debugOled.print(line3);
    }

    drawWifiIconOnDebugOled(WiFi.status() == WL_CONNECTED);

    int8_t percent = parsePercentFromStatusText(line2);
    if (percent < 0) {
        percent = parsePercentFromStatusText(line3);
    }
    drawProgressBarOnDebugOled(percent);

    debugOled.display();
}

void initDebugOled() {
    if (!CAPTAIN_DEBUG_OLED_ENABLED) {
        return;
    }

    const uint8_t candidateAddresses[2] = {
        CAPTAIN_DEBUG_OLED_I2C_ADDRESS_PRIMARY,
        CAPTAIN_DEBUG_OLED_I2C_ADDRESS_SECONDARY
    };

    for (uint8_t address : candidateAddresses) {
        if (!probeI2CAddress(address)) {
            continue;
        }

        if (debugOled.begin(SSD1306_SWITCHCAPVCC, address)) {
            debugOledReady = true;
            debugOledAddress = address;
            Serial.printf("Debug OLED initialized at 0x%02X\n", address);
            writeDebugOledStatus("Boot OK", "5V bring-up", "26V disconnected");
            return;
        }
    }

    Serial.println("Debug OLED detected but failed to initialize as SSD1306");
}

void configureOutputsSafe() {
    for (uint8_t index = 0; index < SOLENOID_COUNT; index++) {
        pinMode(CAPTAIN_SOLENOID_PINS[index], OUTPUT);
        digitalWrite(CAPTAIN_SOLENOID_PINS[index], LOW);
    }
}

void printBringupBanner() {
    const uint32_t fwChecksum = fnv1a32(CAPTAIN_FW_BUILD_ID);

    Serial.println();
    Serial.println("Captain Fantastic control-board bring-up");
    Serial.printf("FW: %s | build=%s | sig=%08lX | built=%s %s\n",
                  CAPTAIN_FW_VERSION,
                  CAPTAIN_FW_BUILD_ID,
                  static_cast<unsigned long>(fwChecksum),
                  __DATE__,
                  __TIME__);
    Serial.printf("Profile: %s\n", CAPTAIN_APP_MODE_NAME);
    Serial.println("Mode: 5 V-only firmware development");
    Serial.println("Note: keep the real 26 V solenoid rail disconnected");
    Serial.printf("I2C: SDA=%u SCL=%u display=0x%02X matrix=0x%02X\n",
                  CAPTAIN_I2C_SDA_PIN,
                  CAPTAIN_I2C_SCL_PIN,
                  CAPTAIN_DISPLAY_I2C_ADDRESS,
                  CAPTAIN_MATRIX_I2C_ADDRESS);
    Serial.printf("Debug OLED candidates: 0x%02X / 0x%02X\n",
                  CAPTAIN_DEBUG_OLED_I2C_ADDRESS_PRIMARY,
                  CAPTAIN_DEBUG_OLED_I2C_ADDRESS_SECONDARY);
    if (debugOledReady) {
        Serial.printf("Debug OLED active at 0x%02X\n", debugOledAddress);
    }
}

void updateHeartbeat(uint32_t now) {
    if (now - lastHeartbeatMs < HEARTBEAT_INTERVAL_MS) {
        return;
    }

    lastHeartbeatMs = now;
    heartbeatState = !heartbeatState;
    setHeartbeatColor(heartbeatState ? 0 : 0, heartbeatState ? 24 : 0, heartbeatState ? 0 : 0);
}

void updateDisplayCounter(uint32_t now) {
    if (now - lastDisplayMs < DISPLAY_INTERVAL_MS) {
        return;
    }

    lastDisplayMs = now;
    updateLEDScore(displayCounter, WiFi.status() == WL_CONNECTED);
    displayCounter = (displayCounter + 111U) % 1000000U;
}

void onDirectInputChanged(uint8_t index, bool asserted, uint32_t now) {
    Serial.printf("Input %s -> %s\n",
                  CAPTAIN_DIRECT_INPUT_NAMES[index],
                  asserted ? "ACTIVE" : "inactive");

    captain::input::overlay::onInputChanged(inputOverlayRuntime,
                                            index,
                                            now,
                                            CAPTAIN_ENABLE_DEEP_INPUT_OVERLAY,
                                            writeDebugOledStatus);
}

void pollDirectInputs(uint32_t now) {
    captain::input::poll(now, INPUT_POLL_MS, onDirectInputChanged);
}

void runOptionalOutputTest(uint32_t now, bool matrixLinkHealthy) {
    if (!CAPTAIN_ENABLE_OUTPUT_TEST) {
        return;
    }

    if (!matrixLinkHealthy && !CAPTAIN_APP_MODE_IS_TEST) {
        if (activeOutput >= 0) {
            digitalWrite(CAPTAIN_SOLENOID_PINS[activeOutput], LOW);
            activeOutput = -1;
            solenoidPulseEndMs = 0;
        }
        return;
    }

    // If a pulse is active and past its end time, turn off the solenoid
    if (activeOutput >= 0 && solenoidPulseEndMs > 0 && now >= solenoidPulseEndMs) {
        digitalWrite(CAPTAIN_SOLENOID_PINS[activeOutput], LOW);
        solenoidPulseEndMs = 0;
    }

    // Check if it's time to start the next solenoid pulse (~500ms between pulses)
    if (now - lastOutputTestMs < OUTPUT_TEST_INTERVAL_MS) {
        return;
    }

    lastOutputTestMs = now;

    // Bench mapping mode: repeatedly pulse only S2 (outhole).
    activeOutput = static_cast<int8_t>(OUTPUT_TEST_SINGLE_SOLENOID);
    digitalWrite(CAPTAIN_SOLENOID_PINS[activeOutput], HIGH);
    
    // Set pulse end time based on the solenoid's configured pulse width (40-45ms)
    solenoidPulseEndMs = now + CAPTAIN_SOLENOID_PULSE_MS[activeOutput];

    // In TEST profile, drive one deterministic matrix lamp blink for clear bench diagnostics.
    if (CAPTAIN_APP_MODE_IS_TEST) {
        matrixLampBlinkOn = !matrixLampBlinkOn;
        captain::protocol::clearLamps(protocolRuntime);
        if (matrixLinkHealthy && matrixLampBlinkOn) {
            const uint8_t lampIndex = static_cast<uint8_t>(activeOutput % MATRIX_LAMP_TEST_COUNT);
            captain::protocol::setLamp(protocolRuntime,
                                       MATRIX_LAMP_TEST_ROWS[lampIndex],
                                       MATRIX_LAMP_TEST_COL,
                                       true);
        }
    }

    Serial.printf("Output test fixed channel: %s\n",
                  CAPTAIN_SOLENOID_NAMES[OUTPUT_TEST_SINGLE_SOLENOID]);

    Serial.printf("Output test -> %s (pulse: %ums)\n",
                  CAPTAIN_SOLENOID_NAMES[activeOutput],
                  static_cast<unsigned>(CAPTAIN_SOLENOID_PULSE_MS[activeOutput]));
    writeDebugOledStatus("Output test", CAPTAIN_SOLENOID_NAMES[activeOutput], "Real pulse timing");
}

void onMatrixSwitchEdge(uint8_t row, uint8_t col, bool closed, uint32_t nowMs) {
    if (!closed) {
        return;
    }

    if (row >= MATRIX_ROWS || col >= MATRIX_COLS) {
        return;
    }

    const uint32_t lastLogged = matrixSwitchLastLoggedMs[row][col];
    if (lastLogged != 0 && (nowMs - lastLogged) < MATRIX_SWITCH_LOG_DEBOUNCE_MS) {
        matrixSwitchSuppressedCount++;
        matrixSwitchSuppressedByCell[row][col]++;
        return;
    }

    if (matrixSwitchLoggedCount >= MATRIX_SWITCH_LOG_MAX_PER_REPORT) {
        matrixSwitchRateLimitedCount++;
        matrixSwitchSuppressedByCell[row][col]++;
        return;
    }

    matrixSwitchLastLoggedMs[row][col] = nowMs;
    matrixSwitchLoggedCount++;

    Serial.printf("Matrix switch closed R%uC%u -> %s\n",
                  static_cast<unsigned>(row),
                  static_cast<unsigned>(col),
                  captainSwitchName(row, col));
}
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
void loop() {
    const uint32_t now = millis();
    captain::ota::maintainWifiConnection(otaRuntime, now, updateOtaStatus);
    updateHeartbeat(now);
    updateDisplayCounter(now);
    captain::matrix::update(matrixRuntime, now, onMatrixSwitchEdge);
    captain::protocol::update(protocolRuntime, now, captain::matrix::isLinkHealthy(matrixRuntime));
    updateMatrixDiagnostics(now);
    pollDirectInputs(now);
    runOptionalOutputTest(now, captain::matrix::isLinkHealthy(matrixRuntime));
    captain::headbox::update(headboxRuntime, now, otaRuntime.inProgress, displayCounter);
    captain::audio::updatePlayback(audioRuntime);
    captain::audio::updateDiagnostic(audioRuntime, now);
    updateIdleOledStatus(now);
    pollSerialAudioCommands();
}

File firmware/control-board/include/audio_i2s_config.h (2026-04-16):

#ifndef AUDIO_I2S_CONFIG_H
#define AUDIO_I2S_CONFIG_H

#include <Arduino.h>
#include "driver/i2s.h"

constexpr i2s_port_t CAPTAIN_AUDIO_I2S_PORT = I2S_NUM_0;
constexpr uint8_t CAPTAIN_AUDIO_DIN_PIN = 25;
constexpr uint8_t CAPTAIN_AUDIO_BCLK_PIN = 14;
constexpr uint8_t CAPTAIN_AUDIO_LRCK_PIN = 13;

// Keep default OFF until hardware routing is physically confirmed.
#ifndef CAPTAIN_AUDIO_SWAP_BCLK_LRCK_FOR_TEST
#define CAPTAIN_AUDIO_SWAP_BCLK_LRCK_FOR_TEST 0
#endif

constexpr uint32_t CAPTAIN_AUDIO_SAMPLE_RATE = 22050;
constexpr uint16_t CAPTAIN_AUDIO_TEST_AMPLITUDE = 1200;

// Bring-up test pattern played on boot to validate MAX98357 wiring/audio path.
constexpr bool CAPTAIN_AUDIO_STARTUP_TEST_ENABLED = true;
constexpr uint8_t CAPTAIN_AUDIO_STARTUP_TEST_REPEATS = 1;
constexpr uint16_t CAPTAIN_AUDIO_STARTUP_TONE_MS = 80;
constexpr uint16_t CAPTAIN_AUDIO_STARTUP_GAP_MS = 30;

// Keeps I2S clocks/data active in short bursts for easier logic-analyzer probing.
constexpr bool CAPTAIN_AUDIO_CONTINUOUS_DIAGNOSTIC = false;
constexpr uint32_t CAPTAIN_AUDIO_CONTINUOUS_INTERVAL_MS = 90;
constexpr uint16_t CAPTAIN_AUDIO_CONTINUOUS_TONE_MS = 45;

// Direct GPIO pulse sanity test before I2S init.
constexpr bool CAPTAIN_AUDIO_PIN_SANITY_TEST = false;
constexpr uint16_t CAPTAIN_AUDIO_PIN_SANITY_PULSE_MS = 2;
constexpr uint16_t CAPTAIN_AUDIO_PIN_SANITY_PULSES = 200;

// Pure GPIO pulse test mode: bypasses all I2S and repeatedly toggles one pin.
constexpr bool CAPTAIN_AUDIO_GPIO_ONLY_TEST_MODE = false;
constexpr uint8_t CAPTAIN_AUDIO_GPIO_ONLY_TEST_PIN = 13;
constexpr uint16_t CAPTAIN_AUDIO_GPIO_ONLY_HALF_PERIOD_MS = 5;

#endif

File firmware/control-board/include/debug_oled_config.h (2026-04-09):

#ifndef DEBUG_OLED_CONFIG_H
#define DEBUG_OLED_CONFIG_H

#include <stdint.h>

// Debug/troubleshooting OLED added to the control board for boot messages
// and bring-up status. This is now identified as a common .96-inch
// SSD1306-style I2C module.
constexpr bool CAPTAIN_DEBUG_OLED_ENABLED = true;
constexpr uint8_t CAPTAIN_DEBUG_OLED_I2C_ADDRESS_PRIMARY = 0x3C;
constexpr uint8_t CAPTAIN_DEBUG_OLED_I2C_ADDRESS_SECONDARY = 0x3D;
constexpr uint16_t CAPTAIN_DEBUG_OLED_WIDTH = 128;
constexpr uint16_t CAPTAIN_DEBUG_OLED_HEIGHT = 64;
constexpr int8_t CAPTAIN_DEBUG_OLED_RESET_PIN = -1;

#endif

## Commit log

2026-04-09 initial commit files as of 4/9/2026
    [Pinball Control board.kicad_pcb, Pinball Control board.kicad_pcb Rev_0.kicad_pcb, Pinball Control board.kicad_sch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]
2026-04-09 inital commit filse for the HAT board
    [Hat board.kicad_pcb, Hat board.kicad_sch, Pinball Control board_Rev_0.kicad_sch]
2026-04-09 Initialize control and HAT board repo
    [Hat board.kicad_pcb, Hat board.kicad_sch, Pinball Control board.kicad_pcb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]
2026-04-09 Organize uploaded KiCad baseline
    [Hat board.kicad_pcb, Hat board.kicad_sch, Pinball Control board.kicad_pcb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]
2026-04-09 Clarify board history and redesign blockers
2026-04-09 Add 5V-only firmware bring-up plan
2026-04-09 Add first 5V power-up checklist
2026-04-09 Start clean control-board firmware migration
2026-04-10 Document smart high-side solenoid direction
2026-04-10 Lock single-channel solenoid layout direction
2026-04-10 Add KiCad note for single-channel solenoid respin
    [Pinball Control board.kicad_sch]
2026-04-10 Define per-channel smart-switch block
2026-04-10 Select TPS1H200A-Q1 for solenoid respin
    [Pinball Control board.kicad_sch]
2026-04-10 Add repo-tracked KiCad library folders and TPS1H200 planning docs
    [Pinball Control board.kicad_sch]
2026-04-10 Add project-local TPS1H200 SnapMagic libraries
    [TPS1H200AQDGNRQ1.step]
2026-04-11 Add first TPS1H200 channel prototype to control board schematic
    [Pinball Control board.kicad_sch]
2026-04-11 Replicate TPS1H200 channels across solenoid outputs
    [Pinball Control board.kicad_sch]
2026-04-11 Ignore KiCad autosave and backup folders
2026-04-11 Align TPS1H200 footprints to project library
    [Pinball Control board.kicad_sch]
2026-04-11 Save routed board checkpoint and order checklist
    [Pinball Control board.kicad_pcb]
2026-04-12 Capture Rev1 order milestone and arrival power-up plan
2026-04-12 Checkpoint KiCad schematic and PCB updates
    [Pinball Control board.kicad_pcb, Pinball Control board.kicad_sch]
2026-04-16 Modularize firmware: extract audio, input, ota, command, headbox runtimes from main.cpp
    - src/audio/audio_runtime.cpp: MP3 playback, I2S, SPIFFS, W25Q128
    - src/input/direct_input_runtime.cpp: pin polling, edge detection
    - src/input/input_overlay_runtime.cpp: OLED overlay timing/text
    - src/ota/ota_runtime.cpp: WiFi, HTTP download, staged OTA apply
    - src/command/command_runtime.cpp: serial dispatcher
    - src/command/{audio,ota,input}_commands: domain command handlers
    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
2026-04-16 Update system behavior contract defaults and board split
2026-04-17 Add board protocol runtime and matrix lamp intent commands
2026-04-17 Add matrix board behavior contract draft
2026-04-17 Lock matrix board contract answers
2026-04-18 docs: align matrix board interface contract
2026-04-28 scripts: add BOM/cross-reference tooling; gitignore build_log and pycache
    [commodity_lookup_template.csv]
2026-04-29 docs: Add firmware integration handoff document for developer transition
    - Complete project state assessment (control ~80%, matrix needs I2C slave)
    - Priority 1-4 roadmap with acceptance criteria
    - Locked technical contracts (register map, GPIO pins, I2C config)
    - Reusable code modules identified
    - Hardware configuration for both boards
    - Testing and validation checklist
    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
2026-05-08 Solenoid bring-up: S2 100ms test pulse, single-channel test mode, GPIO5 init fix, relay workaround handoff
    [main.cpp]
2026-05-11 docs: append switch recovery plan to morning handoff
2026-05-13 Add recovery-to-gameplay integration plan and S2 coil protection policy (May 12–13)
